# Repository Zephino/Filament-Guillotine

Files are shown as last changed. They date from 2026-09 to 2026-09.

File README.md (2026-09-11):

# Filament Guillotine

A filament cutter designed to work with any 3D printer print head. It cuts filament cleanly so toolheads and printers can share or swap filament more reliably.

**Discord:** [https://discord.gg/fSPVZBNUWa](https://discord.gg/fSPVZBNUWa) — development discussion and project updates live here.

## Files

| Folder | Contents |
|---|---|
| `STL/` | Printable STL parts |
| `CAD/` | STEP exports for editing |
| `Filament Guillotine.f3d` | Fusion 360 source |

### Printable parts

- Cutter Housing
- Housing
- Inner Body
- Pusher

## Parts list

Hardware and bought parts will be listed here as they are confirmed.

| Part | Qty | Notes / link |
|---|-----|---|
| KM-1020FN20-103-05185 geared motor | 1 | [AliExpress](https://www.aliexpress.us/item/3256809224168887.html) · [datasheet](docs/KM-1020FN20-103-05185.png) |
| Bolt D2.5 × M2 × 20 mm | 1 | |
| Bolt D2.5 × M2 × 25 mm | 1 | |
| #4 scalpel blade | 1 | AliExpress |

### Motor

N20-style micro DC geared motor with D-shaft output.

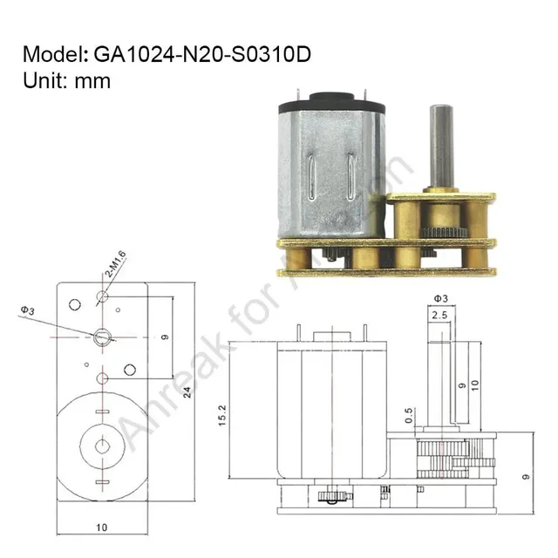
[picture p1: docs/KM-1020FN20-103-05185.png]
KM-1020FN20-103-05185 datasheet


## Status

CAD and STL files are in the repo. Bill of materials is still being collected.

## License

Licensing varies by material. Attribution is required, and derivative works must remain open source under the applicable license.

| Material | License |
|---|---|
| Mechanical CAD, STL/STEP, KiCad/PCB | [CERN-OHL-S-2.0](LICENSES/CERN-OHL-S-2.0.txt) |
| Documentation and images | [CC-BY-SA-4.0](LICENSES/CC-BY-SA-4.0.txt) |
| Scripts (e.g. `kicad/generate_schematic.py`) | [GPL-3.0-or-later](LICENSES/GPL-3.0-or-later.txt) |

Summary:

1. **Attribution.** Credit the authors and link to [this repository](https://github.com/Zephino/Filament-Guillotine).
   - **Zephino** — mechanical design
   - **jrlomas** — KiCad schematics, PCB design, and related electronics
2. **Share-alike.** Projects that use or build on this work must also be released as open source under the matching license above.
3. **Commercial use** is permitted when attribution and share-alike terms are met.

See [`LICENSE`](LICENSE) and [`AUTHORS`](AUTHORS) for full terms.

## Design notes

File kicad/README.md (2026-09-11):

# Guillotine filament-cutter controller

This KiCad 10 project contains the schematic for a compact 24 V electronic
filament-cutter controller. Every purchased component has a PCB footprint and
an `LCSC Part` field; `JP1` is intentionally bare PCB copper.

## Architecture

- `J1` accepts 24 V through JST-XH. `D1` is an SMBJ24A input TVS.
- `U2` (AP63205WU-7) generates 5 V at up to 2 A; `U3` (AMS1117-3.3)
  generates the digital 3.3 V rail. `L2` filters a separate analog 3.3 V rail.
- `U1` is an STM32F072C8T6 in LQFP-48, with an 8 MHz crystal, reset and BOOT0
  buttons, native USB DFU, and a dedicated SWD header.
- `U4` (DRV8870DDAR) drives the 24 V brushed motor. Its 50 mOhm low-side shunt
  sets a 2.2 A hardware current limit and is also measured by `U5`
  (INA180A1), producing 1.0 V/A at `PA0`.
- `U6` is an MT9105ET analog Hall sensor read on `PA1`.
- `U8` (SN65HVD230DR) provides 3.3 V CAN with NUP2105L bus protection.
  Closing `JP1` places `R13`, 120 ohms, across CANH and CANL.
- `U9` (SN74AHCT1G125DBVR) is a genuine TTL-input 3.3-to-5 V level translator
  for the chain of eight edge-mounted WS2812B-2020 RGB LEDs.
- `J5` and `J6` expose separate I2C and SPI buses on solderable headers.

## MCU pin allocation

| Function | STM32 pin |
| --- | --- |
| Motor IN1 / IN2 | PB0 / PB1 |
| Current / Hall ADC | PA0 / PA1 |
| USB D- / D+ | PA11 / PA12 |
| CAN RX / TX | PB8 / PB9 |
| I2C1 SCL / SDA | PB6 / PB7 |
| SPI1 CS / SCK / MISO / MOSI | PA4 / PA5 / PA6 / PA7 |
| NeoPixel data | PA8 |
| SWDIO / SWCLK | PA13 / PA14 |

USB VBUS powers only the USB ESD-protection reference. It is deliberately not
connected to the board's 5 V rail, so plugging in USB cannot back-power the
24 V-powered controller.

The AP63205 is rated for operation only up to 32 V input. The SMBJ24A is pulse
protection for a nominal 24 V rail; it is not a substitute for a regulated 24 V
supply and does not make sustained overvoltage safe.

## PCB layout notes

- Put `D3` through `D10` along the intended visible board edge. Place each
  100 nF bypass capacitor directly beside its LED.
- Route the buck converter input-capacitor, switch-node, inductor, and output-
  capacitor loops first and keep the switch node away from the Hall/ADC nets.
- Use Kelvin connections from both pads of `R5` to `U4`/`U5`. Keep the shunt
  ground return out of the MCU and Hall-sensor ground path.
- Use the specified thermal-via footprint beneath `U4`; connect its exposed pad
  to a generous ground copper area.
- Route USB D+/D- as a short, coupled 90-ohm differential pair. Place `U7` next
  to `J4`. Keep the crystal and its load capacitors tight to `U1`.
- Place `D2`, `R13`, and `JP1` close to the CAN connector. Close `JP1` only when
  this board is at an end of the CAN bus.
- The AMS1117 dissipates `(5 V - 3.3 V) * I3V3`; provide copper area and verify
  its temperature against the final LED-off logic load.

## Regeneration and verification

The checked-in `guillotine-pcb.kicad_sch` is the deliverable. The accompanying
generator requires Python 3, SKiDL 2.3, and the KiCad 10 libraries installed at
the standard macOS application path:

```sh
python generate_schematic.py
```

The final schematic was parsed and exported with KiCad 10.0.4. Error-severity
ERC is clean. KiCad's full ERC reports only library-symbol mismatch warnings
caused by SKiDL's embedded symbol copies differing from the locally installed
library cache; the electrical connections were separately audited from the
exported KiCad netlist.

LCSC identifiers are a sourcing snapshot dated 2026-09-10. Recheck price,
stock, lifecycle, and exact parametric suitability before ordering.

## License

KiCad/PCB design files in this folder are **CERN-OHL-S-2.0** (credit: **jrlomas**).
`generate_schematic.py` is **GPL-3.0-or-later**. See the repository root
[`LICENSE`](../LICENSE) and [`AUTHORS`](../AUTHORS).

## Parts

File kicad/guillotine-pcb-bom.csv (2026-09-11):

Reference | Value | Footprint | QUANTITY | LCSC Part | Manufacturer Part | BOM Note
C1,C20 | 47uF 35V | Capacitor_SMD:CP_Elec_6.3x7.7 | 2 | C424110
C2 | 100nF BST | Capacitor_SMD:C_0402_1005Metric | 1 | C1525
C3 | 10uF 50V | Capacitor_SMD:C_1206_3216Metric | 1 | C13585
C4-C7 | 22uF 10V | Capacitor_SMD:C_0805_2012Metric | 4 | C45783
C8,C10-C14,C17,C22,C24-C34 | 100nF | Capacitor_SMD:C_0402_1005Metric | 19 | C1525
C9 | 1uF | Capacitor_SMD:C_0402_1005Metric | 1 | C52923
C15,C16 | 33pF | Capacitor_SMD:C_0402_1005Metric | 2 | C1562
C18 | 10nF VREF filter | Capacitor_SMD:C_0402_1005Metric | 1 | C15195
C19 | 100nF 50V | Capacitor_SMD:C_0603_1608Metric | 1 | C14663
C21,C23 | 100nF ADC filter | Capacitor_SMD:C_0402_1005Metric | 2 | C1525
D1 | SMBJ24A | Diode_SMD:D_SMB | 1 | C123819 | SMBJ24A
D2 | NUP2105L CAN TVS | Package_TO_SOT_SMD:SOT-23 | 1 | C284104 | NUP2105L
D3-D10 | WS2812B-2020 EDGE | LED_SMD:LED_WS2812B-2020_PLCC4_2.0x2.0mm | 8 | C965555 | WS2812B-2020
J1 | 24V POWER (JST-XH) | Connector_JST:JST_XH_B2B-XH-A_1x02_P2.50mm_Vertical | 1 | C158012 | B2B-XH-A(LF)(SN)
J2 | DC MOTOR (JST-XH) | Connector_JST:JST_XH_B2B-XH-A_1x02_P2.50mm_Vertical | 1 | C158012 | B2B-XH-A(LF)(SN)
J3 | CAN (JST-XH) | Connector_JST:JST_XH_B3B-XH-A_1x03_P2.50mm_Vertical | 1 | C144394 | B3B-XH-A(LF)(SN)
J4 | USB-C PROGRAM/DFU | Connector_USB:USB_C_Receptacle_HRO_TYPE-C-31-M-12 | 1 | C165948 | TYPE-C-31-M-12
J5 | I2C SOLDERABLE HEADER | Connector_PinHeader_2.54mm:PinHeader_1x04_P2.54mm_Vertical | 1 | C124378 | B-2100S04P-A110
J6 | SPI SOLDERABLE HEADER | Connector_PinHeader_2.54mm:PinHeader_1x06_P2.54mm_Vertical | 1 | C124380 | B-2100S06P-A110
J7 | SWD PROGRAM HEADER | Connector_PinHeader_1.27mm:PinHeader_1x05_P1.27mm_Vertical | 1 | C22438102 | HX PZ1.27-1x5P ZZ
JP1 | SOLDER CLOSED = 120R CAN TERM | Jumper:SolderJumper-2_P1.3mm_Open_RoundedPad1.0x1.5mm | 1 |  |  | PCB copper; no purchased part
L1 | 4.7uH >=3A | Inductor_SMD:L_Taiyo-Yuden_NR-60xx | 1 | C42428085 | ZENR6028T4R7M-4.7uH
L2 | 120R @ 100MHz ferrite | Inductor_SMD:L_0603_1608Metric | 1 | C113030 | BLM18SG121TN1D
R1,R4 | 10k | Resistor_SMD:R_0402_1005Metric | 2 | C25744
R2 | 10k BOOT0 pull-down | Resistor_SMD:R_0402_1005Metric | 1 | C25744
R3 | 20k | Resistor_SMD:R_0402_1005Metric | 1 | C25765
R5 | 0.05R 3W shunt | Resistor_SMD:R_2512_6332Metric | 1 | C500743
R6,R7 | 1k ADC filter | Resistor_SMD:R_0402_1005Metric | 2 | C11702
R8 | 5.1k CC1 | Resistor_SMD:R_0402_1005Metric | 1 | C25905
R9 | 5.1k CC2 | Resistor_SMD:R_0402_1005Metric | 1 | C25905
R10 | 22R USB D+ | Resistor_SMD:R_0402_1005Metric | 1 | C25092
R11 | 22R USB D- | Resistor_SMD:R_0402_1005Metric | 1 | C25092
R12 | 0R high-speed CAN | Resistor_SMD:R_0402_1005Metric | 1 | C17168
R13 | 120R CAN TERM | Resistor_SMD:R_1206_3216Metric | 1 | C17909
R14 | 33R NeoPixel data | Resistor_SMD:R_0402_1005Metric | 1 | C25105
R15 | 4.7k I2C SCL pull-up | Resistor_SMD:R_0402_1005Metric | 1 | C25900
R16 | 4.7k I2C SDA pull-up | Resistor_SMD:R_0402_1005Metric | 1 | C25900
SW1 | RESET | Button_Switch_SMD:SW_SPST_PTS810 | 1 | C221895 | PTS810SJG250SMTRLFS
SW2 | BOOT/DFU | Button_Switch_SMD:SW_SPST_PTS810 | 1 | C221895 | PTS810SJG250SMTRLFS
U1 | STM32F072C8T6 | Package_QFP:LQFP-48_7x7mm_P0.5mm | 1 | C80488 | STM32F072C8T6
U2 | AP63205WU-7 (5V/2A) | Package_TO_SOT_SMD:TSOT-23-6 | 1 | C2071056 | AP63205WU-7
U3 | AMS1117-3.3 | Package_TO_SOT_SMD:SOT-223-3_TabPin2 | 1 | C6186 | AMS1117-3.3
U4 | DRV8870DDAR 3.6A H-bridge | Package_SO:Texas_HTSOP-8-1EP_3.9x4.9mm_P1.27mm_EP2.95x4.9mm_Mask2.4x3.1mm_ThermalVias | 1 | C86590 | DRV8870DDAR
U5 | INA180A1IDBVR (20V/V) | Package_TO_SOT_SMD:SOT-23-5 | 1 | C122228 | INA180A1IDBVR
U6 | MT9105ET analog Hall 5mV/G | Package_TO_SOT_SMD:SOT-23 | 1 | C967861 | MT9105ET
U7 | USBLC6-2SC6 USB ESD | Package_TO_SOT_SMD:SOT-23-6 | 1 | C7519 | USBLC6-2SC6
U8 | SN65HVD230DR 3.3V CAN | Package_SO:SOIC-8_3.9x4.9mm_P1.27mm | 1 | C12084 | SN65HVD230DR
U9 | SN74AHCT1G125DBVR | Package_TO_SOT_SMD:SOT-23-5 | 1 | C7484 | SN74AHCT1G125DBVR
Y1 | 8MHz 20pF | Crystal:Crystal_SMD_3225-4Pin_3.2x2.5mm | 1 | C2682774 | X32258MSB4SI

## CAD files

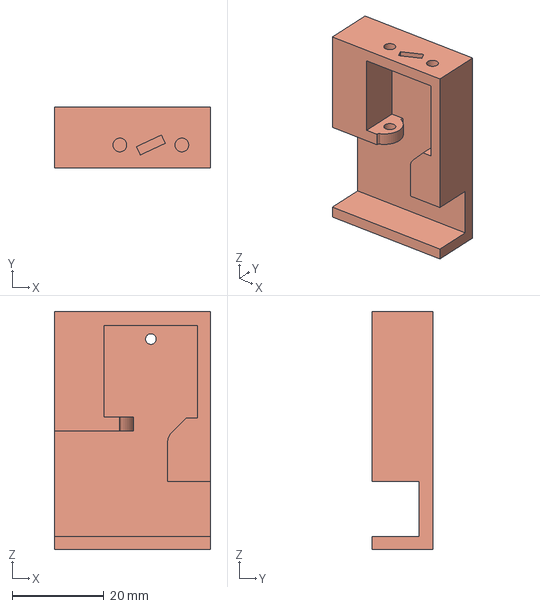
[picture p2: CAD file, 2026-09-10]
CAD/Filament Guillotine-Inner Boddy.step
34.0 x 13.3 x 51.8 mm

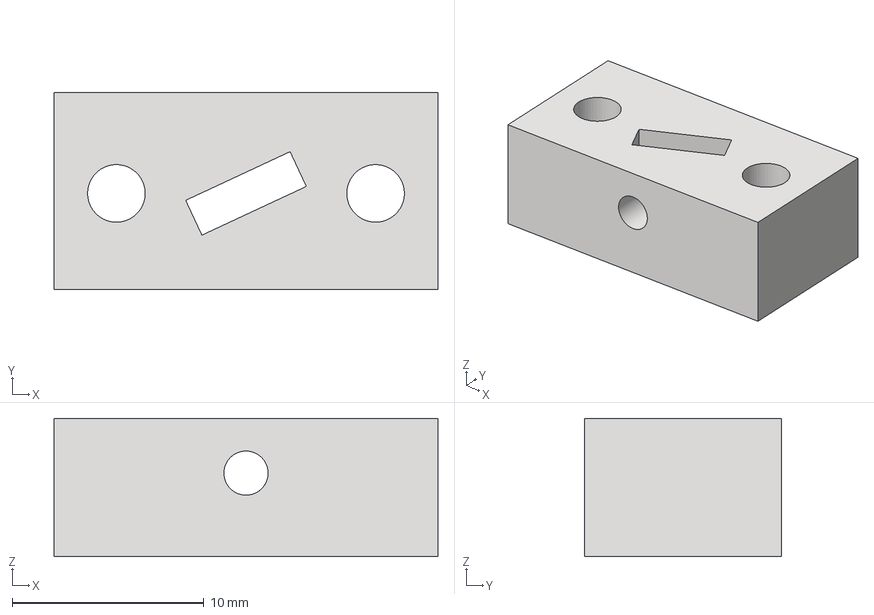
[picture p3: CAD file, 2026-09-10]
CAD/Filament Guillotine-Cutter Housing.step
20.0 x 10.2 x 7.20 mm

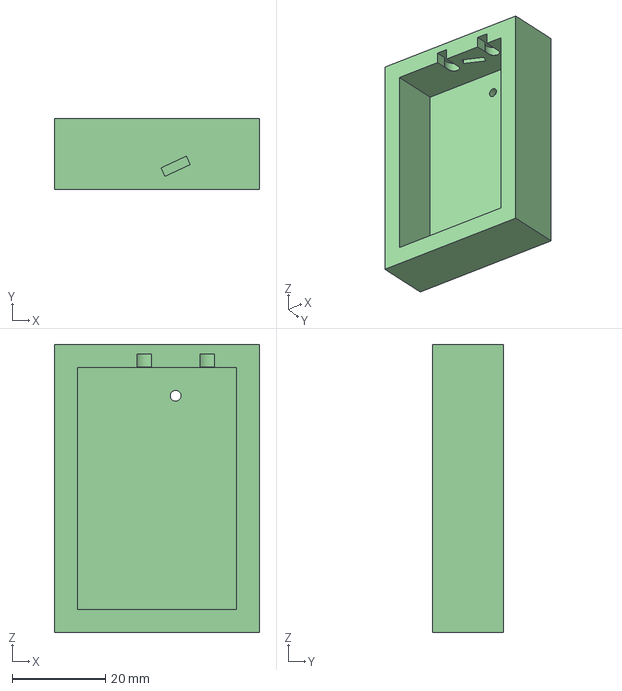
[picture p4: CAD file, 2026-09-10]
CAD/Filament Guillotine-Housing.step
44.0 x 15.2 x 61.8 mm

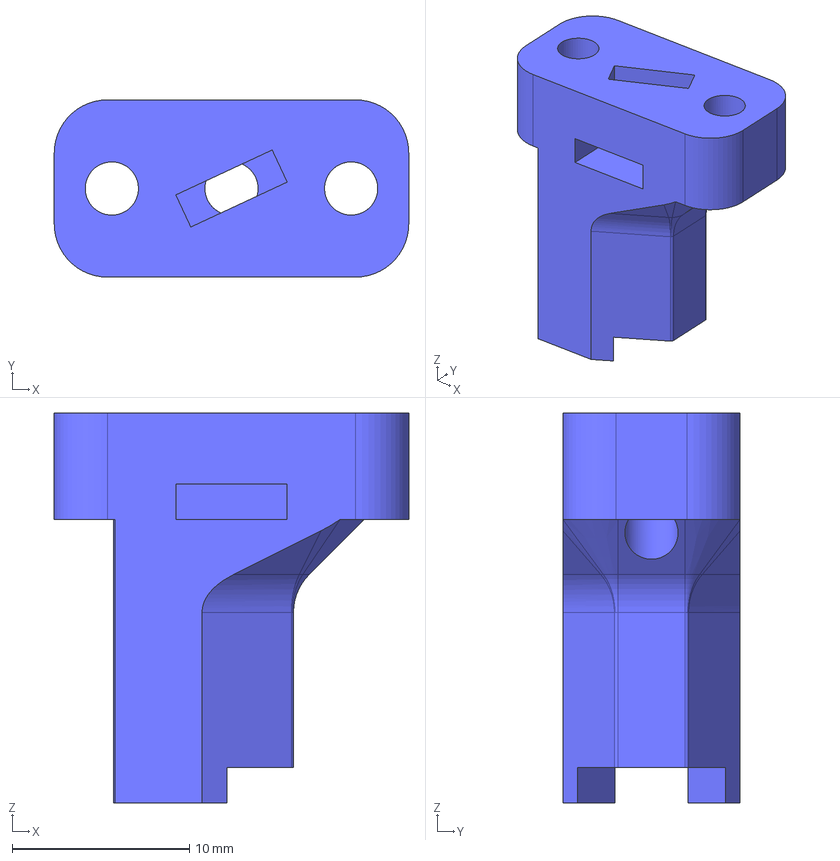
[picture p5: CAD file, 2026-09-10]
CAD/Filament Guillotine-Pusher.step
20.0 x 10.0 x 22.0 mm

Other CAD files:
Filament Guillotine.f3d
STL/Filament Guillotine-Cutter Housing.stl
STL/Filament Guillotine-Housing.stl
STL/Filament Guillotine-Inner Boddy.stl
STL/Filament Guillotine-Pusher.stl

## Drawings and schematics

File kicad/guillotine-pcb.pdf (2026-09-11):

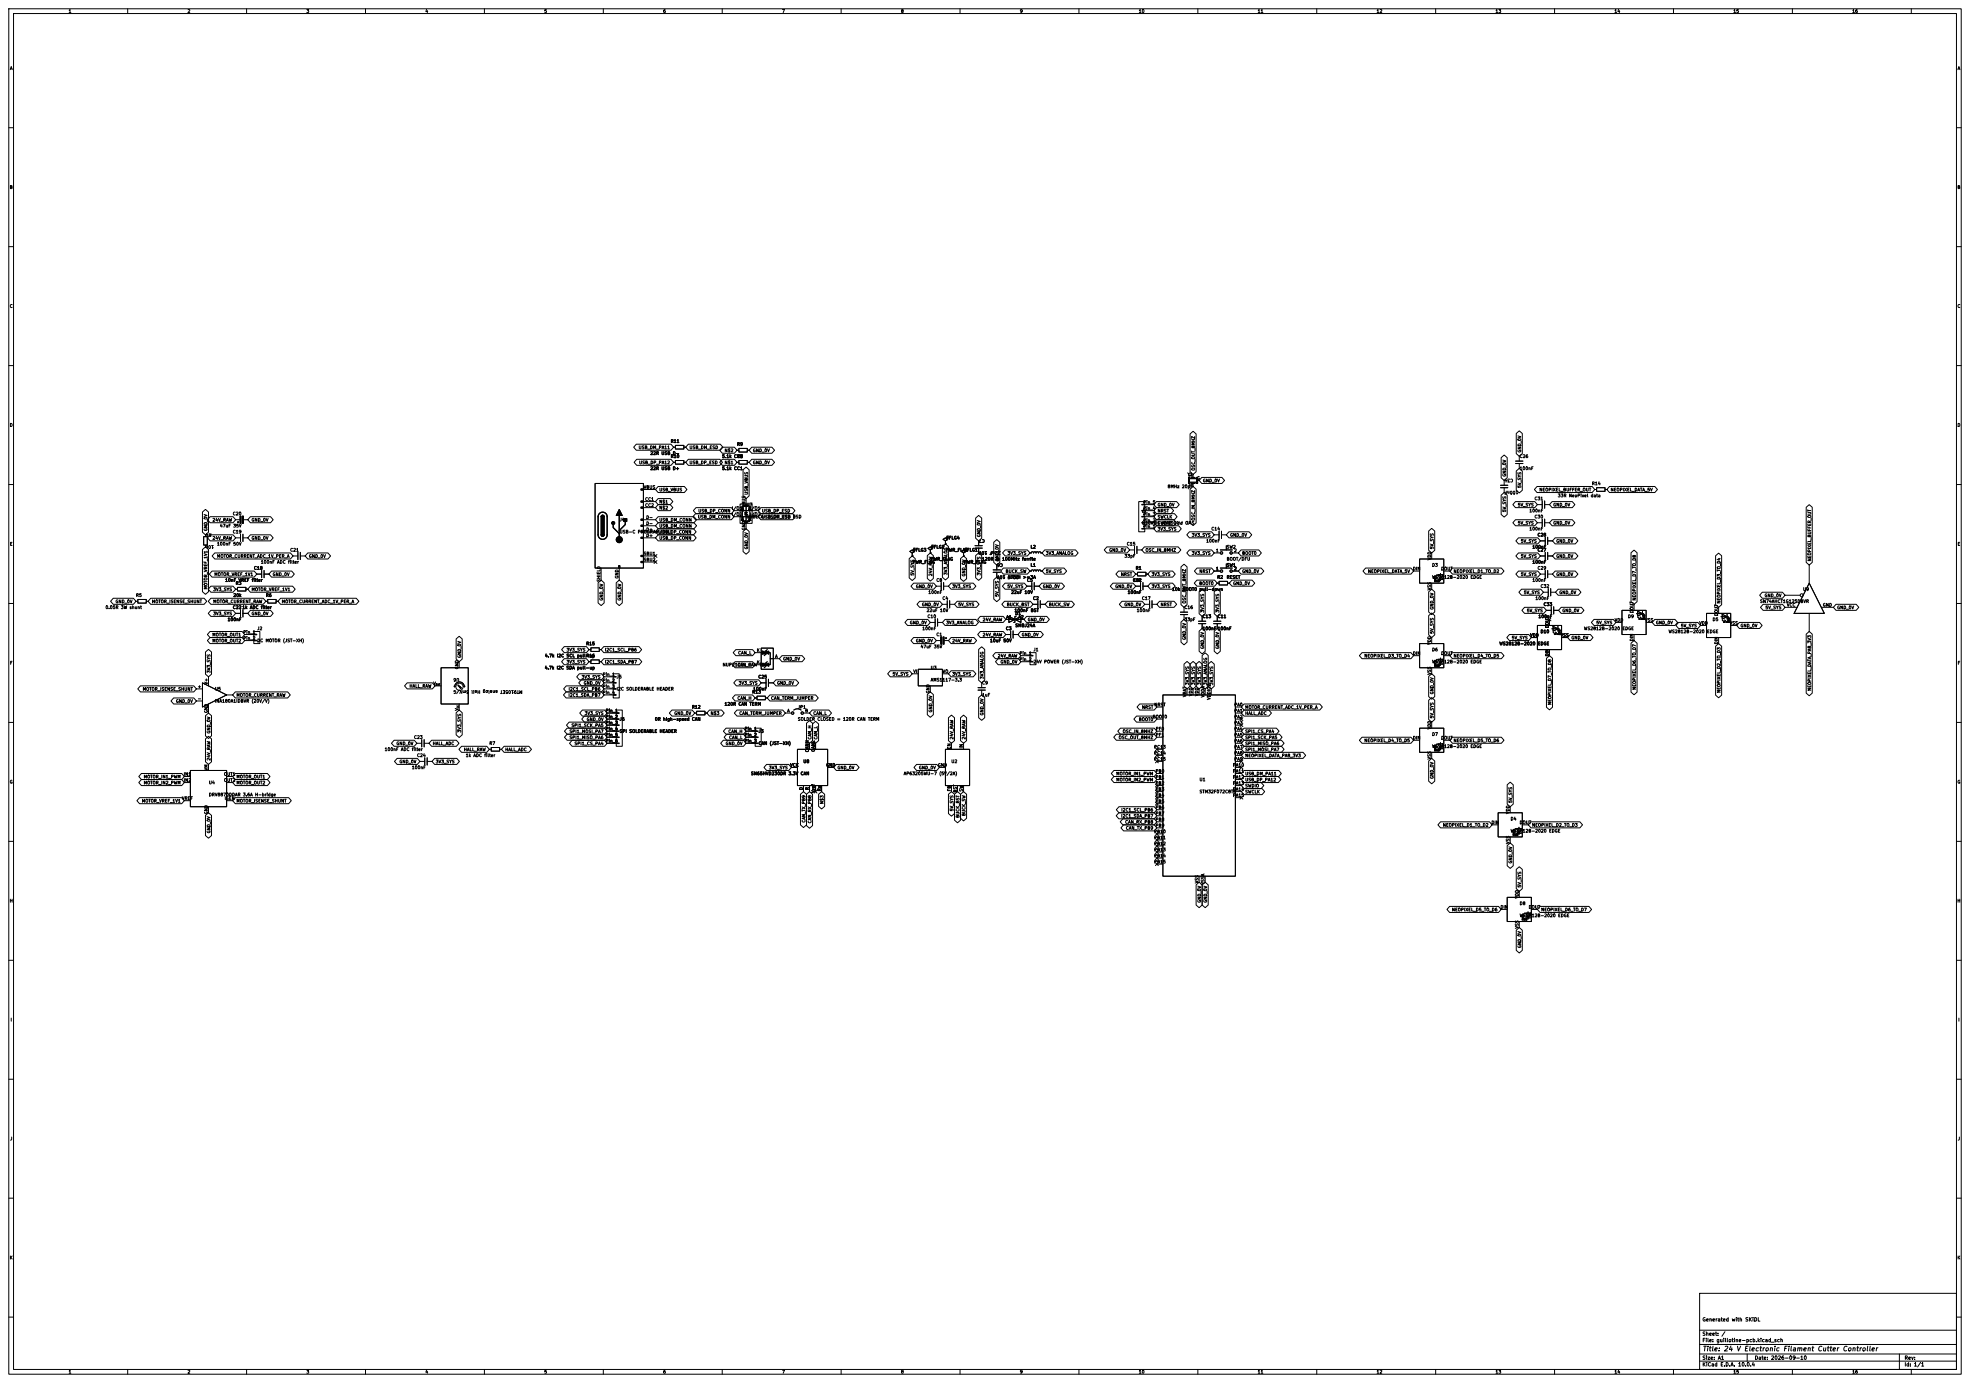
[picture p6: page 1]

SOLDER CLOSED = 120R CAN TERM

RVref CANH CANL Rs U8

RVref CANH CANL Rs

Sheet: /
File: guillotine-pcb.kicad_sch
Title: 24 V Electronic Filament Cutter Controller

Size: A1 | Rev:
KiCad E.D.A. 10.0.4 | Id: 1/1

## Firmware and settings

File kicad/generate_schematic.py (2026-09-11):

#!/usr/bin/env python3
# SPDX-License-Identifier: GPL-3.0-or-later
# Copyright (c) jrlomas
"""Generate the guillotine controller schematic with SKiDL/KiCad 10 libraries.

The checked-in .kicad_sch is the deliverable.  This source is kept so that
net assignments, footprints, and LCSC selections remain easy to audit.
"""

from __future__ import annotations

import os
import importlib
import builtins
import subprocess
from pathlib import Path


KICAD_ROOT = Path("/Applications/KiCad/KiCad.app/Contents/SharedSupport")
KICAD_CLI = Path("/Applications/KiCad/KiCad.app/Contents/MacOS/kicad-cli")
SYMBOL_DIR = KICAD_ROOT / "symbols"
FOOTPRINT_DIR = KICAD_ROOT / "footprints"

os.environ.setdefault("KICAD_SYMBOL_DIR", str(SYMBOL_DIR))
for version in (6, 7, 8, 9, 10):
    os.environ.setdefault(f"KICAD{version}_SYMBOL_DIR", str(SYMBOL_DIR))
os.environ.setdefault("KICAD10_FOOTPRINT_DIR", str(FOOTPRINT_DIR))
os.environ.setdefault("MPLCONFIGDIR", "/tmp/guillotine-skidl-mpl")

from skidl import (  # noqa: E402
    KICAD10,
    Group,
    POWER,
    Part,
    Net,
    generate_schematic,
    set_default_tool,
)
from skidl.net import NCNet  # noqa: E402


set_default_tool(KICAD10)

# With a label-only drawing, SKiDL's two-pin snap pass is counterproductive:
# it may insert a residual wire between nearby power pins after those nets have
# already been classified as stubs.  Disable that pass so every connection is
# represented only by its unambiguous global label.
kicad10_generator = importlib.import_module("skidl.tools.kicad10.gen_schematic")
kicad10_generator._snap_two_pin_parts = lambda node: None


def component(
    lib: str,
    name: str,
    ref: str,
    *,
    value: str | None = None,
    footprint: str | None = None,
    lcsc: str | None = None,
    mpn: str | None = None,
) -> Part:
    """Create a part and attach the sourcing fields used by the BOM."""
    kwargs = {"ref": ref}
    if value is not None:
        kwargs["value"] = value
    if footprint is not None:
        kwargs["footprint"] = footprint
    part = Part(lib, name, tool=KICAD10, **kwargs)
    if lcsc:
        part.fields["LCSC Part"] = lcsc
    if mpn:
        part.fields["Manufacturer Part"] = mpn
    return part


def resistor(ref: str, value: str, lcsc: str, *, size: str = "0402") -> Part:
    metric = {
        "0402": "0402_1005Metric",
        "0603": "0603_1608Metric",
        "1206": "1206_3216Metric",
        "2512": "2512_6332Metric",
    }[size]
    return component(
        "Device",
        "R_Small",
        ref,
        value=value,
        footprint=f"Resistor_SMD:R_{metric}",
        lcsc=lcsc,
    )


def capacitor(
    ref: str,
    value: str,
    lcsc: str,
    *,
    size: str = "0402",
    polarized: bool = False,
) -> Part:
    if polarized:
        return component(
            "Device",
            "C_Polarized_Small",
            ref,
            value=value,
            footprint="Capacitor_SMD:CP_Elec_6.3x7.7",
            lcsc=lcsc,
        )
    metric = {
        "0402": "0402_1005Metric",
        "0603": "0603_1608Metric",
        "0805": "0805_2012Metric",
        "1206": "1206_3216Metric",
    }[size]
    return component(
        "Device",
        "C_Small",
        ref,
        value=value,
        footprint=f"Capacitor_SMD:C_{metric}",
        lcsc=lcsc,
    )


def connect_cap(cap: Part, rail: Net, gnd: Net) -> None:
    rail += cap[1]
    gnd += cap[2]


def no_connect_unused(part: Part) -> None:
    """Place explicit no-connect markers on every still-unused pin."""
    unused = [pin for pin in part.pins if not pin.is_connected()]
    if unused:
        nc = NCNet(f"{part.ref}_UNUSED")
        nc += unused


# Named nets are deliberately used throughout.  The generated drawing places
# matching labels at pins, keeping a dense one-sheet schematic unambiguous.
# Use explicit global-label names instead of KiCad's power-symbol aliases.
# This keeps every rail connection mechanically identical in the generated
# drawing and avoids orientation-dependent power-symbol placement.
gnd = Net("GND_0V")
v24 = Net("24V_RAW")
v5 = Net("5V_SYS")
v33 = Net("3V3_SYS")
v33a = Net("3V3_ANALOG")
for rail in (gnd, v24, v5, v33, v33a):
    rail.drive = POWER

# KiCad ERC needs explicit power-output sources for connector-fed rails and
# regulator outputs.  These symbols are schematic-only and never enter the BOM.
for rail in (gnd, v24, v5, v33a):
    pwr_flag = Part("power", "PWR_FLAG", tool=KICAD10)
    rail += pwr_flag[1]


# ---------------------------------------------------------------------------
# 24 V entry, 5 V synchronous buck, and 3.3 V LDO.
# ---------------------------------------------------------------------------
j1 = component(
    "Connector_Generic",
    "Conn_01x02",
    "J1",
    value="24V POWER (JST-XH)",
    footprint="Connector_JST:JST_XH_B2B-XH-A_1x02_P2.50mm_Vertical",
    lcsc="C158012",
    mpn="B2B-XH-A(LF)(SN)",
)
v24 += j1[1]
gnd += j1[2]

d1 = component(
    "Device",
    "D_TVS",
    "D1",
    value="SMBJ24A",
    footprint="Diode_SMD:D_SMB",
    lcsc="C123819",
    mpn="SMBJ24A",
)
v24 += d1[1]
gnd += d1[2]

c1 = capacitor("C1", "47uF 35V", "C424110", polarized=True)
connect_cap(c1, v24, gnd)

u2 = component(
    "Regulator_Switching",
    "AP63205WU",
    "U2",
    value="AP63205WU-7 (5V/2A)",
    footprint="Package_TO_SOT_SMD:TSOT-23-6",
    lcsc="C2071056",
    mpn="AP63205WU-7",
)
v24 += u2[2, 3]  # EN and IN.
gnd += u2[4]
v5 += u2[1]  # Fixed-output FB sense.
buck_sw = Net("BUCK_SW")
buck_bst = Net("BUCK_BST")
buck_sw += u2[5]
buck_bst += u2[6]

l1 = component(
    "Device",
    "L_Small",
    "L1",
    value="4.7uH >=3A",
    footprint="Inductor_SMD:L_Taiyo-Yuden_NR-60xx",
    lcsc="C42428085",
    mpn="ZENR6028T4R7M-4.7uH",
)
buck_sw += l1[1]
v5 += l1[2]

c2 = capacitor("C2", "100nF BST", "C1525")
buck_bst += c2[1]
buck_sw += c2[2]
c3 = capacitor("C3", "10uF 50V", "C13585", size="1206")
connect_cap(c3, v24, gnd)
for ref in ("C4", "C5"):
    connect_cap(capacitor(ref, "22uF 10V", "C45783", size="0805"), v5, gnd)

u3 = component(
    "Regulator_Linear",
    "AMS1117-3.3",
    "U3",
    value="AMS1117-3.3",
    footprint="Package_TO_SOT_SMD:SOT-223-3_TabPin2",
    lcsc="C6186",
    mpn="AMS1117-3.3",
)
gnd += u3[1]
v33 += u3[2]
v5 += u3[3]
connect_cap(capacitor("C6", "22uF 10V", "C45783", size="0805"), v5, gnd)
connect_cap(capacitor("C7", "22uF 10V", "C45783", size="0805"), v33, gnd)
connect_cap(capacitor("C8", "100nF", "C1525"), v33, gnd)

l2 = component(
    "Device",
    "L_Small",
    "L2",
    value="120R @ 100MHz ferrite",
    footprint="Inductor_SMD:L_0603_1608Metric",
    lcsc="C113030",
    mpn="BLM18SG121TN1D",
)
v33 += l2[1]
v33a += l2[2]
connect_cap(capacitor("C9", "1uF", "C52923"), v33a, gnd)
connect_cap(capacitor("C10", "100nF", "C1525"), v33a, gnd)
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

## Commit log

2026-09-10 Initial commit: Filament Guillotine CAD and STL files.
    [Filament Guillotine-Cutter Housing.step, Filament Guillotine-Cutter Housing.stl, Filament Guillotine-Housing.step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]
2026-09-10 Document GA1024-N20-S0310D motor with datasheet image.
2026-09-10 Correct motor model to KM-1020FN20-103-05185.
2026-09-11 Initial commit given the motor requirements. Intermediate commit. TOOD: Review and arrange the netlists correctly as to make the schematic much more readable
    [guillotine-pcb-bom.csv, guillotine-pcb.kicad_pcb, guillotine-pcb.kicad_sch]
2026-09-11 Fully corrected schematic
    [guillotine-pcb.kicad_sch]
2026-09-11 Credit jrlomas for KiCad and PCB work in the license.
2026-09-11 Tighten README license wording for a cleaner presentation.
